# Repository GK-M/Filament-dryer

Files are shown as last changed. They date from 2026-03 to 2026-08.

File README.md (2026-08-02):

# Filament Dryer

**🇬🇧 English** · [🇵🇱 Polski](README.pl.md)

A 250 W heated drying chamber for 3D-printing filament, built from scratch: mechanics designed in
Autodesk Inventor and 3D-printed, electronics wired on a prototype board, firmware written for an
ESP32-C3 — first as a single Arduino sketch, then rewritten on **FreeRTOS** with tasks, queues and
over-the-air updates.

<p align="center">
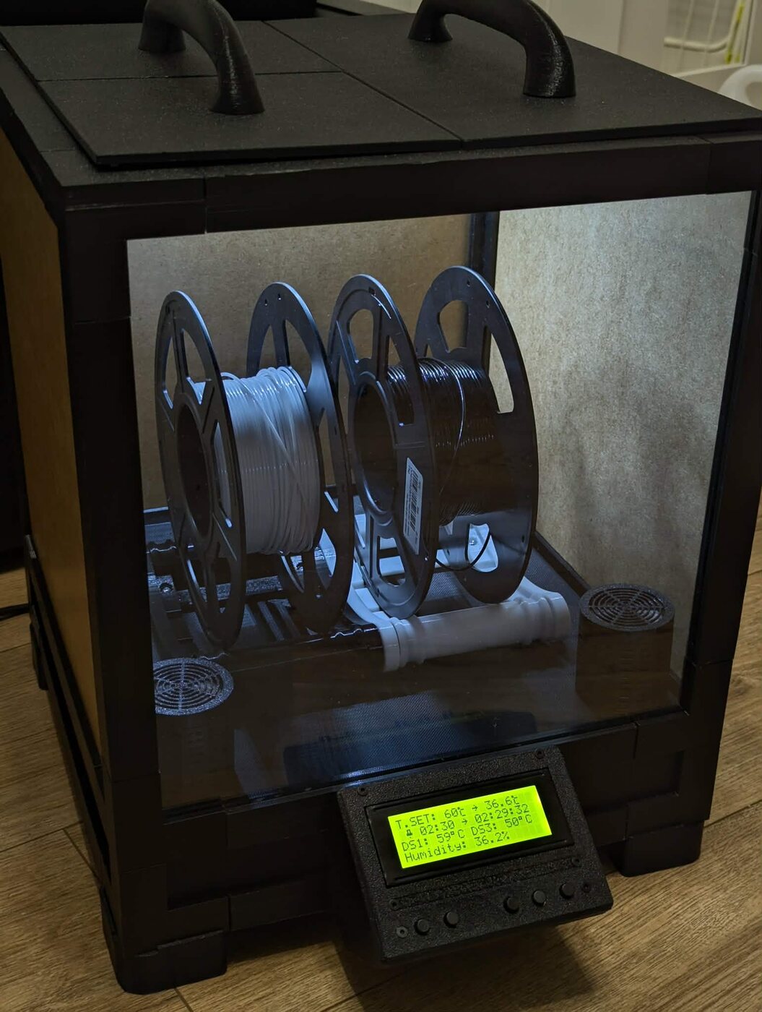
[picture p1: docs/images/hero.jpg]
Assembled filament dryer with two spools inside
  
</p>

<p align="center">
  
  
  
  
  
</p>

---

## Table of contents

| Document | What is inside |
|---|---|
| **[📸 Build log](docs/en/build-log.md)** | Photos from the whole build, stage by stage |
| [🔧 Hardware](docs/en/hardware.md) | Bill of materials, pin map, power rails, CAD & STL files |
| [💻 Firmware](docs/en/firmware.md) | FreeRTOS task/queue architecture, PID loop, UI, OTA |
| [📝 Changelog](docs/en/changelog.md) | What changed between v1, v2 and v3 |
| [🗺️ Roadmap](docs/en/roadmap.md) | Planned features and known issues |

---

## What it does

Wet filament prints badly — stringing, popping, weak layer adhesion. This box heats a sealed chamber
to a set temperature, holds it with a PID loop, and runs for a time you dial in on the front panel.

* **Set a temperature** (0–100 °C in 5 °C steps; ~70 °C is the practical ceiling of the enclosure)
* **Set a drying time** (15 min per click, up to 24 h) — the heater switches off when it elapses
* **Watch everything live** on a 20×4 LCD: chamber temperature, humidity, mat temperatures,
  PWM duty, remaining time, Wi-Fi status
* **Tune the PID on the device** — Kp/Ki/Kd are edited with the buttons and stored in flash,
  so they survive a reboot
* **Flash new firmware without a cable** — ArduinoOTA over Wi-Fi

## How it works

```
                 ┌──────────── ESP32-C3 ────────────┐
  AHT10  ──I²C──▶│  chamber temp ──▶ PID ──▶ PWM ───┼──▶ MOSFET ──▶ 3× heating mat (250 W)
  BMP280 ──I²C──▶│  temp / pressure                 │
                 │                                  │
 3× DS18B20 ─1W─▶│  mat temp ──▶ over-temp cut-off ─┼──▶ setpoint forced to 0
                 │                                  │
  5× button ─IRQ▶│  UI state machine ───────────────┼──▶ LCD 20×4 (I²C)
                 │                                  ├──▶ fan PWM (humidity driven)
        Wi-Fi ──▶│  ArduinoOTA                      └──▶ LED strip PWM
                 └──────────────────────────────────┘
```

The PID acts on the **chamber air temperature** (AHT10). The DS18B20 sensors sit on the heating mats
and are used purely for safety: if any of them passes **110 °C** the setpoint and PWM output are
forced to zero, and heating is only re-armed once all mats drop below **70 °C**.

Full details: **[Firmware architecture](docs/en/firmware.md)** · **[Hardware](docs/en/hardware.md)**

## Key specifications

| | |
|---|---|
| Controller | ESP32-C3 (`esp32-c3-devkitm-1`), Arduino framework, FreeRTOS |
| Heating | 3× silicone mat 24 V with heatsinks — 2×100 W + 1×50 W = **250 W** |
| Max chamber temperature | ~70 °C |
| Process sensor | AHT10 (temperature + relative humidity) |
| Auxiliary sensors | BMP280 (temperature, pressure), 3× DS18B20 (mat / electronics temperature) |
| Actuator drive | MOSFET modules, LEDC PWM 20 kHz, 10-bit resolution |
| Power rails | 24 V (mats) · 12 V (fan, LED) · 5 V (ESP32), via DC-DC step-down converters |
| Interface | LCD 20×4 I²C @ `0x27`, 5 buttons, LED chamber lighting |
| Connectivity | Wi-Fi, ArduinoOTA firmware updates |
| Enclosure | 3D-printed PETG frame + 300×300 mm acrylic panels |

## Repository layout

```
filament-dryer/
├── docs/
│   ├── en/            English documentation
│   ├── pl/            Polish documentation
│   ├── images/        Build photos
│   └── media/         Build video
├── firmware/
│   ├── v1-arduino/    Original single-file Arduino sketch (kept for reference)
│   └── v3-freertos/   Current PlatformIO project — FreeRTOS, OTA, NVS
└── hardware/
    ├── v1/cad/        Inventor parts & assemblies, STEP, 3MF
    └── v2/stl/        Printable STL files (base, screen mount)
```

## Building the firmware

The current firmware is a [PlatformIO](https://platformio.org/) project.

```bash
git clone https://github.com/GK-M/Filament_dryer.git
cd Filament_dryer/firmware/v3-freertos

# Wi-Fi credentials are not in the repository — create them from the template
cp include/secrets.h.example include/secrets.h
$EDITOR include/secrets.h

pio run                 # build
pio run -t upload       # flash (OTA by default — see below)
pio device monitor      # serial log
```

`platformio.ini` is configured for **OTA upload** to a fixed address:

```ini
upload_protocol = espota
upload_port = 192.168.1.15
```

For the first flash — or any time the board is not on the network — comment those two lines out and
upload over USB. The static IP is also set in `src/main.cpp`; change both to match your network.

## Status

v1 and v2 are complete and working. **v3 is under active development** — the firmware runs, but a
few screens and the fan control loop are still unfinished. Everything known to be incomplete or
buggy is listed openly in the [roadmap](docs/en/roadmap.md#known-issues).

## Licence

Released under the [MIT Licence](LICENSE).

> ⚠️ **Safety note.** This device draws 250 W of heating power and runs unattended for hours.
> The firmware over-temperature cut-off is a software safeguard, not a substitute for a proper
> thermal fuse, an adequately rated power supply and correctly sized wiring. Build and use at your
> own risk.

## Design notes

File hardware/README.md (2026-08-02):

# Hardware

Full documentation: **[English](../docs/en/hardware.md)** · **[Polski](../docs/pl/sprzet.md)**

```
v1/cad/   Autodesk Inventor parts (.ipt) and assemblies (.iam),
          plus neutral STEP (.stp) exports and sliced 3MF files.
v2/stl/   Printable STL files from version 2.
```

## Print settings

| Part | Material | Notes |
|---|---|---|
| Frame, corners, brackets | PETG | ~1 kg total for the full set |
| Display mount (`screen_mount.stl`, `screen_v2.stl`) | **ABS** | sits near the warm chamber wall; PETG softens there |
| Base (`base.stl`) | PETG | v2 perforation pattern — improves airflow and warm-up time |

## A note on filenames

The Inventor files keep their original Polish names. Inventor assemblies reference their component
parts *by filename*, so renaming any `.ipt` would break every `.iam` that uses it. An English
translation table is in the [hardware documentation](../docs/en/hardware.md#cad-sources--hardwarev1cad).

If you only want to print, use the `.stp` and `.3mf` files — they stand alone.

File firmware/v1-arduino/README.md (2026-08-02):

# Firmware v1 — Arduino sketch

*Historical. Kept for reference; superseded by [v3](../v3-freertos/).*

The original firmware: a single 729-line `.ino` file with one `loop()` handling sensor reads, the PID
loop, LCD redraws and button polling in sequence.

It worked and dried filament, but it showed the limits of the approach:

* the LCD flickered on every full redraw
* button presses were dropped while the display was being written
* every new feature had to be woven into the same growing loop
* configuration was spread across dozens of `#define`s and globals

Those problems are what motivated the [FreeRTOS rewrite](../v3-freertos/). Reading the two side by
side is the clearest illustration of what the rewrite bought.

## Building

Open `filament_dryer_v1.ino` in the Arduino IDE, select an ESP32-C3 board, and install:

`LiquidCrystal_I2C` · `Adafruit AHTX0` · `Adafruit BMP280` · `OneWire` · `DallasTemperature` ·
`PID by Brett Beauregard`

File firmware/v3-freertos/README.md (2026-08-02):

# Firmware v3 — FreeRTOS

*Current firmware. See [architecture documentation](../../docs/en/firmware.md) · [dokumentacja architektury](../../docs/pl/firmware.md).*

PlatformIO project for the ESP32-C3, Arduino framework, built on FreeRTOS.

## Quick start

```bash
cp include/secrets.h.example include/secrets.h   # add your Wi-Fi credentials
pio run                                          # build
pio run -t upload                                # flash
pio device monitor                               # serial log
```

`platformio.ini` uploads over the air by default. For the **first flash**, or whenever the board is
not reachable on the network, comment out these two lines and connect over USB:

```ini
upload_protocol = espota
upload_port = 192.168.1.15
```

The same static IP is set in `src/main.cpp` — change both to match your network.

## Layout

```
include/
├── config.h            pins, timings, calibration constants, LCD glyphs
├── rtos_handles.h      queue/task handles, shared data structures, enums
├── secrets.h           Wi-Fi credentials — GIT-IGNORED, create it yourself
├── secrets.h.example   template for the above
└── tasks/              one header per task
src/
├── main.cpp            queue and task creation, Wi-Fi, OTA
└── tasks/
    ├── button_task.cpp   ISR, debounce, auto-repeat, UI state machine
    ├── control_task.cpp  PID loop, PWM output, over-temperature cut-off
    ├── display_task.cpp  all LCD screens, countdown
    ├── fan_task.cpp      fan PWM
    ├── led_task.cpp      chamber LED PWM
    ├── log_task.cpp      serialises log messages onto Serial
    └── sensor_task.cpp   DS18B20, AHT10, BMP280
```

## Dependencies

Resolved automatically by PlatformIO from `platformio.ini`:

| Library | Purpose |
|---|---|
| `paulstoffregen/OneWire` | 1-Wire bus |
| `milesburton/DallasTemperature` | DS18B20 |
| `adafruit/Adafruit BMP280 Library` | BMP280 |
| `adafruit/Adafruit AHTX0` | AHT10 |
| `marcoschwartz/LiquidCrystal_I2C` | LCD 20×4 |
| `br3ttb/PID` | PID controller |

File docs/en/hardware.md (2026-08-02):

# Hardware

[← back to README](../../README.md) · [🇵🇱 wersja polska](../pl/sprzet.md)

---

## Bill of materials

### Electronics

| Qty | Part | Notes |
|:--:|---|---|
| 1 | ESP32-C3 dev board | `esp32-c3-devkitm-1`, Wi-Fi + USB CDC |
| 3 | MOSFET module | low-side switching of the heating mats |
| 3 | DC-DC step-down converter | generates the 12 V and 5 V rails from 24 V |
| 1 | AHT10 | I²C temperature + relative humidity — **PID process sensor** |
| 1 | BMP280 | I²C temperature + pressure |
| 3 | DS18B20 | 1-Wire, on the heating mats / electronics bay — safety cut-off |
| 1 | LCD 20×4 with I²C backpack | address `0x27` |
| 5 | Push button | menu navigation, momentary, to GND |
| 1 | Rocker switch | mains ON/OFF |
| 1 | Prototype board | carries the ESP32 and the wiring |
| 1 | LED strip | chamber lighting, PWM dimmable |
| 1 | Fan, 120 mm | air circulation, PWM controlled |
| 1 | Power supply, 250 W / 24 V | sized for all three mats at once |
| 1 | XT60 connector | main DC feed |
| — | Wire | sized for 24 V / ~10 A on the heater side |

### Heating

| Qty | Part |
|:--:|---|
| 2 | Silicone heating mat 100 W / 24 V |
| 1 | Silicone heating mat 50 W / 24 V |
| 3 | Heatsink (one per mat) |

### Mechanics

| Qty | Part |
|:--:|---|
| ~1 kg | PETG filament (frame, brackets, mounts) |
| — | ABS filament (display mount, v2 onwards — see [changelog](changelog.md)) |
| — | Acrylic sheet 300×300 mm |

---

## Power rails

```
        ┌── 24 V ──▶ 3× heating mat (via MOSFET modules)
 PSU ───┼── 12 V ──▶ fan + LED strip        (DC-DC step-down)
 250 W  └──  5 V ──▶ ESP32-C3               (DC-DC step-down)
```

The 24 V rail must carry the full 250 W of heating (≈10.4 A) — this is the part of the build where
wire gauge and connector rating actually matter.

---

## Pin map

Defined in [`firmware/v3-freertos/include/config.h`](../../firmware/v3-freertos/include/config.h).

| Function | GPIO | Notes |
|---|:--:|---|
| 1-Wire bus (3× DS18B20) | 3 | shared bus, sensors addressed individually |
| Heater PWM | 2 | LEDC channel 0, 20 kHz, 10-bit |
| Fan PWM | 4 | LEDC channel 2, 20 kHz, 10-bit |
| LED strip PWM | 7 | LEDC channel 1, 20 kHz, 10-bit |
| I²C SDA | 8 | 400 kHz — LCD, AHT10, BMP280 |
| I²C SCL | 9 | |
| Button — Enter | 1 | next screen |
| Button — Mode | 5 | cycles operating mode |
| Button — Screen | 10 | selects which value is being edited |
| Button — Decrease | 20 | with auto-repeat on hold |
| Button — Increase | 21 | with auto-repeat on hold |

All buttons are wired to GND and use the internal pull-ups (`INPUT_PULLUP`), so a press reads LOW.

### DS18B20 addresses

The 1-Wire sensors are addressed explicitly rather than by bus index, so swapping cables cannot
silently reassign which sensor is which. The addresses live in the `adrr_DS` namespace in
`config.h`; if you build your own unit, read your sensors' ROM codes and replace them there.

---

## Sensor roles

| Sensor | Measures | Used for |
|---|---|---|
| AHT10 | chamber air temperature, RH | **PID input** and fan control |
| BMP280 | temperature, pressure | display / logging only |
| DS18B20 ×3 | heating mat and electronics temperature | over-temperature safety cut-off |

The distinction matters: the PID regulates the *air*, not the mats. The mats always run hotter than
the chamber, which is exactly why they need their own independent safety sensors.

---

## Enclosure

The chamber is a 3D-printed frame holding 300×300 mm acrylic panels, rather than a fully printed
box. It uses far less filament, prints in manageable pieces, and lets you see the spools.

### CAD sources — `hardware/v1/cad/`

Autodesk Inventor parts (`.ipt`) and assemblies (`.iam`), with neutral `.stp` exports and sliced
`.3mf` files alongside them.

> **Filenames are intentionally left in Polish.** Inventor assemblies reference their component
> parts by filename — renaming the `.ipt` files would break every `.iam`. The table below is the
> translation key.

| Folder / file | English |
|---|---|
| `Front plexa/` | front acrylic panel |
| `obramówka do plexy/` | acrylic frame trim |
| `tył tył boxa/` | rear of the box |
| `tył za plexą/` | rear section, behind the acrylic |
| `OldVersions/` | superseded revisions |
| `Kątownik …` | angle bracket |
| `Narożnik …` | corner piece |
| `Klin_do_łączenia_34mm` | 34 mm joining wedge |
| `Koniec BOXa` | box end cap |
| `Część 1 / 2 / 3` | part 1 / 2 / 3 |
| `… na kabel` / `… przelotka` | with cable pass-through / grommet |
| `… z dziurą` | with hole |
| `… 3 wcięcia` | with three notches |
| `… x2`, `x3`, `x3szt` | print 2×, 3× |
| `górny` / `dolny` / `środek` | top / bottom / middle |
| `prawy` / `lewy` | right / left |

### Printable STL — `hardware/v2/stl/`

| File | Part | Material |
|---|---|---|
| `base.stl` | chamber base, v2 perforation pattern | ABS |
| `screen_mount.stl` | display mount | **ABS** (PETG deforms near the warm wall) |
| `screen_v2.stl` | display bezel, v2 | ABS |

---

## Assembly notes

* Fit the DS18B20 sensors in **direct contact** with the mats, under the heatsinks — an air gap
  makes the safety cut-off react far too late.
* Keep the 24 V heater wiring physically away from the I²C lines. The mats switch at 20 kHz and will
  happily inject noise into a long, unshielded I²C run.
* The AHT10 should sit in moving air away from the mats, otherwise the PID chases a hot spot instead
  of the chamber temperature.
* Route the mains side so the switch cuts everything upstream of the PSU.

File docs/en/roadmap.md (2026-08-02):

# Roadmap

[← back to README](../../README.md) · [🇵🇱 wersja polska](../pl/plany.md)

---

## Done

- [x] Drying timer
- [x] Over-temperature protection — setpoint forced to zero when a mat exceeds the limit
- [x] Dedicated display task
- [x] Firmware updates over Wi-Fi (ArduinoOTA)
- [x] PID gains editable on the device and persisted to flash
- [x] Wi-Fi status icon on the LCD

## Next

- [ ] **Fan control from humidity** — replace the current threshold with a proper control law
- [ ] **LED control** — hold *Enter* to toggle the backlight and the chamber LED together
- [ ] **Cooldown countdown** — when `pid_data.error` is set, show how long until the mats are back
      under the safe threshold instead of a static fault screen
- [ ] **Fault screen** — finish the `TEMP_ERROR` layout
- [ ] **Operating modes** — presets per filament type (PLA / PETG / ABS / Nylon) behind the
      `Mode` button, which currently only cycles an unused enum

## Later

- [ ] **MQTT or raw TCP/IP** — report state to a server
- [ ] **Remote control** — set temperature and time from outside the device
- [ ] **Notifications on completion** — PC, phone, e-mail
- [ ] **Double-walled chamber** — better insulation, faster warm-up, lower energy use
- [ ] **Filament feed-through** — let the printer draw filament straight from the dryer
- [ ] **Second, smaller fan** — improve moisture extraction

---

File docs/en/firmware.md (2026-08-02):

# Firmware

[← back to README](../../README.md) · [🇵🇱 wersja polska](../pl/firmware.md)

---

## Two generations

The firmware exists in two forms, both kept in the repository on purpose.

**[`firmware/v1-arduino/`](../../firmware/v1-arduino/)** — the original: one 729-line `.ino` file,
a single `loop()` doing sensor reads, PID, display refresh and button polling in sequence. It worked,
but the display flickered, button presses were missed while the LCD was being redrawn, and adding
anything meant threading it through the same loop.

**[`firmware/v3-freertos/`](../../firmware/v3-freertos/)** — the rewrite. Every concern became its
own FreeRTOS task, communicating through queues, with interrupt-driven buttons, persistent settings
and OTA updates. That is what this document describes.

---

## Task architecture

```mermaid
graph LR
    subgraph Inputs
        BTN[Button task<br/>prio 20]
        DS[DS18B20 task<br/>prio 6, 1 s]
        I2CS[AHT10/BMP280 task<br/>prio 5, 500 ms]
    end

    subgraph Logic
        CTRL[Control task<br/>prio 8, 10 ms]
    end

    subgraph Outputs
        DISP[Display task<br/>prio 15, 25 ms]
        FAN[Fan task<br/>prio 3]
        LED[LED task<br/>prio 2]
        LOG[Log task<br/>prio 11]
        OTA[OTA task<br/>prio 8]
    end

    BTN -->|xSetpointQueue| CTRL
    BTN -->|xDisplayQueue<br/>xTimerQueue| DISP
    DS -->|xDS18B20Queue| CTRL
    I2CS -->|xI2CsensorsQueue| CTRL
    I2CS -->|xI2CsensorsQueue| FAN
    CTRL -->|xControlDataQueue| DISP
    DS --> DISP
    I2CS --> DISP
    CTRL -.->|LOG| LOG
```

| Task | Priority | Stack | Period | Responsibility |
|---|:--:|:--:|:--:|---|
| `vButtonTask` | 20 | 16384 | event | Debounce, auto-repeat, UI state machine, NVS writes |
| `vDisplayTask` | 15 | 8192 | 25 ms | Renders all LCD screens, runs the countdown |
| `vLogTask` | 11 | 2048 | blocking | Serialises log messages onto `Serial` |
| `vControlTask` | 8 | 4096 | 10 ms | PID loop, PWM output, over-temperature cut-off |
| `vOtaTask` | 8 | 2048 | 100 ms | `ArduinoOTA.handle()`, Wi-Fi reconnect |
| `vTempSensorTask` | 6 | 2048 | 1 s | Reads the three DS18B20 sensors |
| `vHumTempSensorTask` | 5 | 4096 | 500 ms | Reads AHT10 and BMP280 over I²C |
| `vFanTask` | 3 | 1024 | 100 ms | Fan PWM from chamber humidity |
| `vLedTask` | 2 | 1024 | 50 ms | Chamber LED PWM |

`loop()` deletes itself with `vTaskDelete(NULL)` — the Arduino loop task is not used at all.

### Why these priorities

The button task sits highest because a missed press is immediately obvious to the user, while a
sensor reading arriving 20 ms late is not. Sensors sit low because they are periodic and tolerant of
jitter. The logger sits above the control loop deliberately: it must be able to drain its queue even
when everything else is busy, otherwise log messages are silently dropped exactly when you most want
to read them.

---

## Inter-task communication

Every queue except the log and button queues has **depth 1** and is written with `xQueueOverwrite`
and read with `xQueuePeek`. This is a deliberate pattern: these queues carry *current state*, not
events. A consumer always sees the newest value, a producer never blocks, and a slow consumer cannot
build a backlog of stale readings.

| Queue | Depth | Payload | Producer → consumer |
|---|:--:|---|---|
| `xDS18B20Queue` | 1 | `DS_sensors` | sensor → control, display |
| `xI2CsensorsQueue` | 1 | `I2C_sensors` | sensor → control, display, fan |
| `xSetpointQueue` | 1 | `PID_data` | button, control → control, display |
| `xControlDataQueue` | 1 | `Control_status` | control → display |
| `xTimerQueue` | 1 | `Timer_data` | button, display → display |
| `xDisplayQueue` | 1 | `Display_data` | button → display |
| `xButtonQueue` | 10 | `ButtonRAW` | **ISR** → button task |
| `xLogQueue` | 10 | `char[LOG_MSG_LEN]` | all tasks → log task |

The button and log queues are true event queues, so they are deeper and are drained with
`xQueueReceive`.

### The I²C mutex

The LCD, AHT10 and BMP280 all share one I²C bus, and the display task and sensor task run at
different rates and priorities. `xI2CMutex` guards every transaction; without it a display refresh
interleaving with a sensor read corrupts both.

---

## Control loop

```c
pid.SetTunings(Kp, Ki, Kd);
pid.Input = i2c_sensors.temp_aht;   // chamber air temperature
pid.Compute();
ledcWrite(0, pid.Output);           // 0..1023 → MOSFET → heating mats
```

* Library: `br3ttb/PID` in `DIRECT` mode
* Output range `0..1023`, matching the 10-bit LEDC resolution
* Sample time 10 ms
* Default gains `Kp = 2.25`, `Ki = 0.05`, `Kd = 0.0` — editable on the device, capped at
  `Kp ≤ 20`, `Ki ≤ 10`, `Kd ≤ 5`

`SetTunings()` is called on every iteration so that gains edited on the LCD take effect immediately,
without restarting the loop.

When the setpoint drops to zero the PID is briefly switched to `MANUAL`, its output forced to zero,
and switched back to `AUTOMATIC`. This resets the integral term — otherwise accumulated windup would
make the heater kick back on the moment a new setpoint is dialled in.

### Over-temperature protection

```
any DS18B20 > 110 °C  →  setpoint = 0, output = 0, error = true
all DS18B20 <  70 °C  →  error = false   (heating may resume)
```

The hysteresis band between the two thresholds is what stops the system oscillating in and out of
its fault state. Thresholds live in `Calibration::Max_DS_temperature` and
`Calibration::Temp_after_error` in `config.h`.

---

## Timer

The drying timer counts in `Timer_data`, incremented in 15-minute steps
(`Calibration::Button_Add_Time`) and clamped to 24 hours. It starts as soon as a non-zero time is
first dialled in, and the countdown itself runs inside the display task. When it reaches zero the
setpoint is zeroed and the UI switches to the `DONE` screen.

---

## User interface

Five buttons, all interrupt-driven. The ISR does the minimum possible — capture pin, edge and
timestamp, push into `xButtonQueue`, yield:

```c
void IRAM_ATTR isrButton(void* arg) {
    ButtonRAW event;
    event.pin  = (uint32_t)arg;
    event.edge = (digitalRead(event.pin) == LOW) ? PRESSED : RELEASED;
    event.timestamp = millis();
    xQueueSendFromISR(xButtonQueue, &event, &woken);
}
```

Debouncing (150 ms) and hold-to-repeat (400 ms) are handled in the task, not the ISR.

### Screens

| Screen | Shows |
|---|---|
| `Main` | Setpoint, chamber temperature, timer, countdown, DS18B20 readings, humidity, Wi-Fi icon |
| `Sensors_data` | Raw values from every sensor |
| `PID_cook` | Kp / Ki / Kd editor, live temperature and PWM duty |
| `PID_fan` | Placeholder — fan PID not implemented |
| `DONE` | Drying finished |
| `TEMP_ERROR` | Over-temperature fault |
| `MODE` | Operating mode — placeholder |

**Enter** advances the screen, **Screen** selects which value on that screen is being edited
(shown by a `>` marker), **Increase** / **Decrease** change it, **Mode** cycles the operating mode.

### Custom LCD glyphs

`config.h` defines six 5×8 characters: a degree symbol, a bell for the timer, two halves of a Wi-Fi
icon, and two halves of a crossed-out Wi-Fi icon for the disconnected state.

---

## Persistence

PID gains are stored in NVS through the `Preferences` API and reloaded at boot by the control,
display and button tasks. Changing a gain writes it immediately — so a tuning session survives a
power cut, and the dryer comes back with the gains you actually arrived at.

---

## Wi-Fi and OTA

A static IP (`192.168.1.15`) is configured in `main.cpp`, and `ArduinoOTA` runs under the hostname
`Filament Dryer`. The OTA task also handles reconnection: if the link drops, it retries every five
seconds. **Wi-Fi is never blocking** — the dryer boots, heats and regulates perfectly well with no
network at all, and the LCD simply shows the crossed-out Wi-Fi icon.

Credentials live in `include/secrets.h`, which is git-ignored. Copy `include/secrets.h.example` and
fill in your own.

---

## Known issues

Openly tracked in the [roadmap](roadmap.md#known-issues) rather than hidden.

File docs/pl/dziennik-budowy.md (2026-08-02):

# Dziennik budowy

[← powrót do README](../../README.pl.md) · [🇬🇧 English version](../en/build-log.md)

Zdjęcia z budowy wersji 1, mniej więcej w kolejności, w jakiej powstawała. Zmiany z wersji 2 są na
końcu.

---

## 1. Prototyp na płytce stykowej

Zanim cokolwiek powstało w CAD-zie, cała elektronika została złożona na blacie: ESP32-C3,
wyświetlacz, czujniki I²C i moduły MOSFET połączone luźnymi przewodami — tak, żeby sprawdzić
przypisanie pinów i odczyty czujników na działającym ekranie.

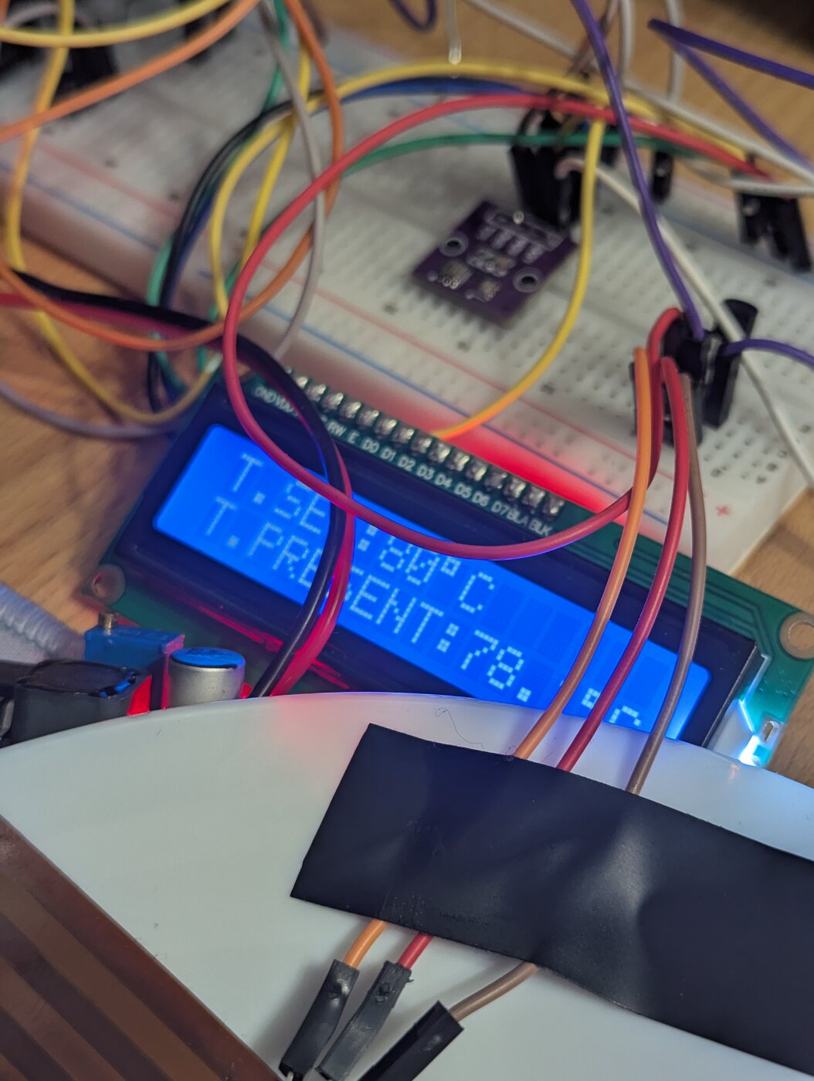
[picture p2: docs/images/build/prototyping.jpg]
Prototyp elektroniki na stole warsztatowym


To z tego etapu bierze się mapa pinów w
[`config.h`](../../firmware/v3-freertos/include/config.h) — piny zostały wybrane właśnie tutaj i
później już się nie zmieniały.

---

## 2. Druk ramy

Obudowa nie jest drukowanym pudełkiem. To zestaw drukowanych narożników i profili krawędziowych,
które spinają panele z pleksi 300×300 mm — zdecydowanie mniej filamentu, dużo krótszy czas druku
i komora, do której faktycznie widać.

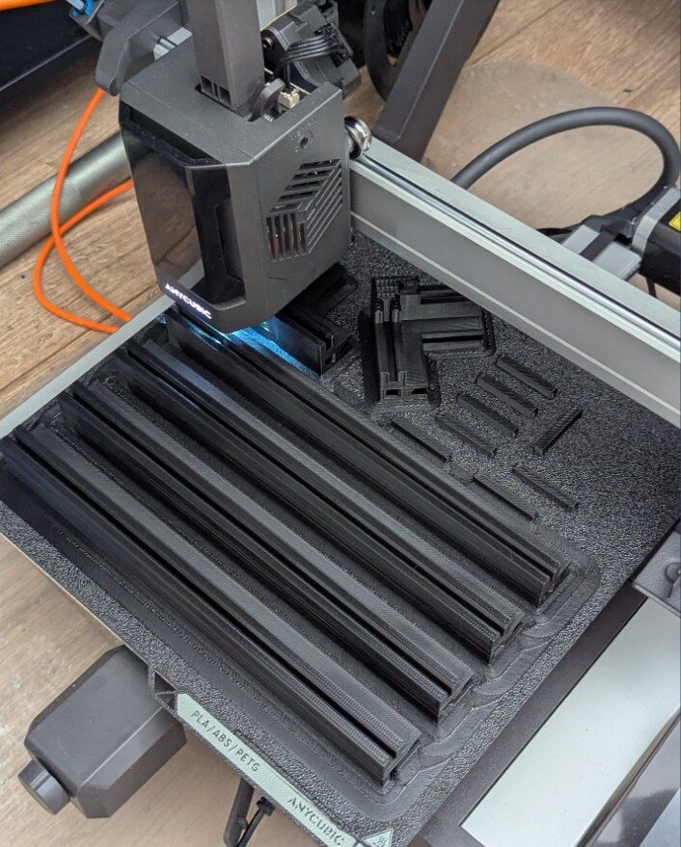
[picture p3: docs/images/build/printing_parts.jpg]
Elementy ramy na stole drukarki


Każda część została narysowana w Autodesk Inventor; pliki źródłowe są w
[`hardware/v1/cad/`](../../hardware/v1/cad/).

---

## 3. Wydrukowane części

Komplet narożników, kątowników i łączników rozłożony przed montażem. Kilka części ma po kilka
wersji — te nieaktualne leżą w folderach `OldVersions/` zamiast zostać skasowane, żeby historia
projektowania pozostała widoczna.

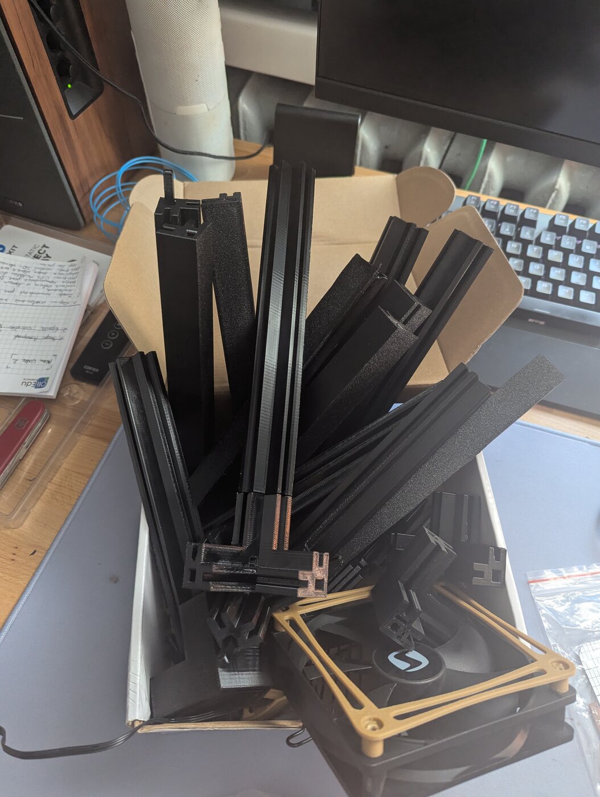
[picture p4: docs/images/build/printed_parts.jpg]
Zestaw wydrukowanych elementów ramy


---

## 4. Montaż obudowy

Rama i panele z pleksi składane w gotową komorę.

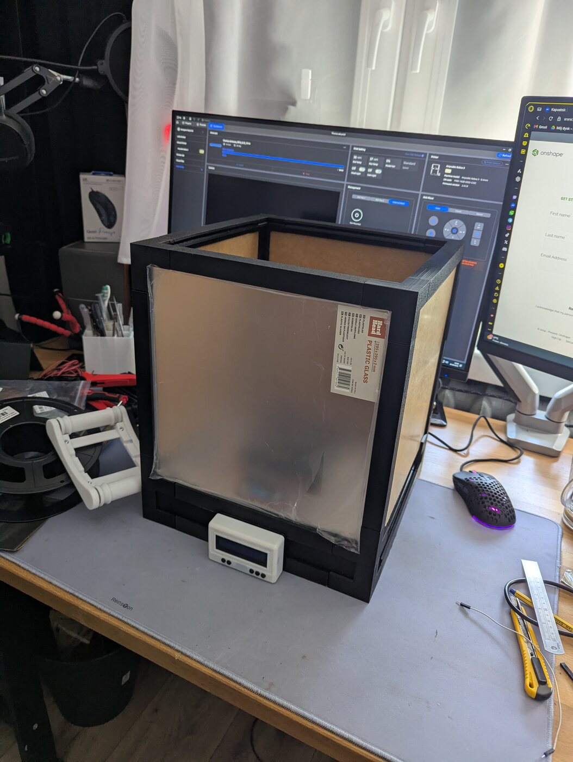
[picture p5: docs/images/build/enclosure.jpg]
Złożona obudowa


---

## 5. Wnętrze komory

Rozplanowanie środka: gdzie usiądą maty grzewcze wraz z radiatorami, jak przechodzi obok nich
powietrze i jak podeprzeć szpule, żeby swobodnie się obracały.

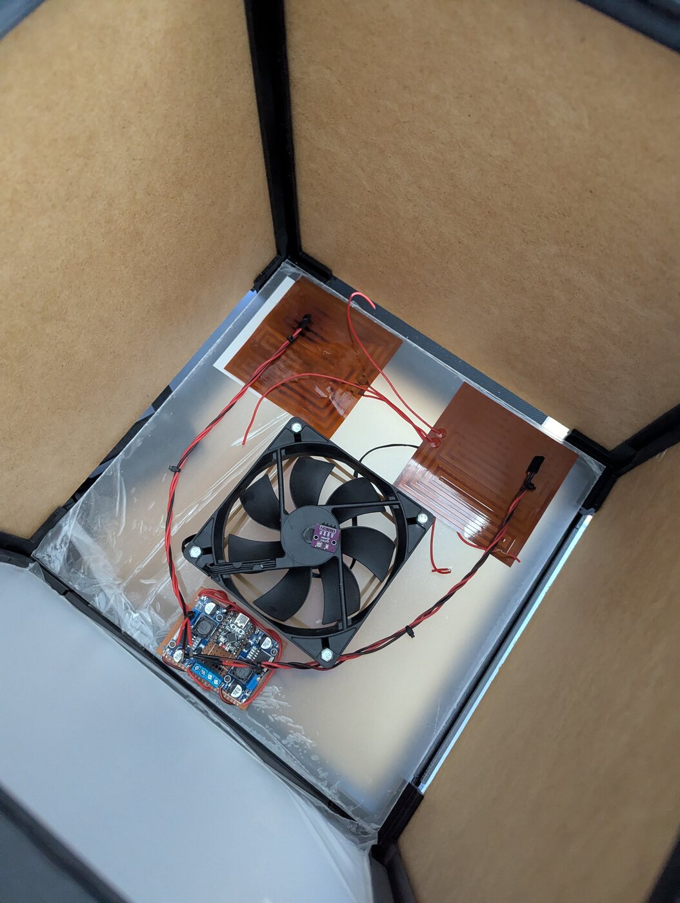
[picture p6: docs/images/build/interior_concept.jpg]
Wnętrze komory


---

## 6. Płytka sterownika i wyświetlacz

Elektronika przeniosła się ze stykówki na płytkę prototypową, a wyświetlacz trafił do drukowanego
mocowania na panelu przednim.

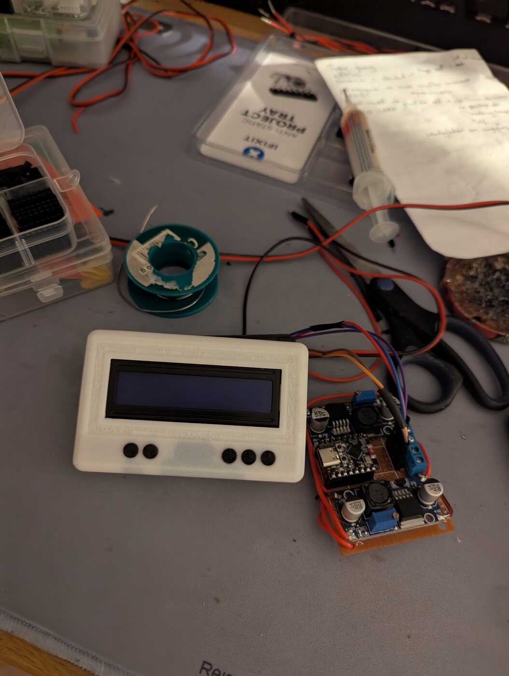
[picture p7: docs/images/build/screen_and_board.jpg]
Wyświetlacz i płytka sterownika


**Film:** [przegląd płytki sterownika](../media/controller_board.mp4) *(2,6 MB, bez dźwięku)*

<a href="../media/controller_board.mp4">
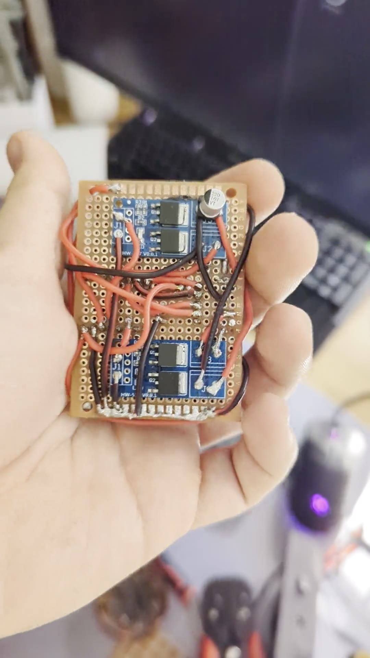
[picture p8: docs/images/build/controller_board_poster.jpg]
Kadr z filmu z płytką sterownika
  
</a>

---

## 7. Bezpieczeństwo

250 W grzania pracujące bez nadzoru przez wiele godzin wymaga szacunku. Przewody zostały dobrane pod
prąd, maty dostały własne czujniki DS18B20, a firmware — twarde zabezpieczenie termiczne, które
zeruje setpoint przy 110 °C i nie pozwala wrócić do grzania, dopóki każda mata nie spadnie poniżej
70 °C. Zobacz [`control_task.cpp`](../../firmware/v3-freertos/src/tasks/control_task.cpp).

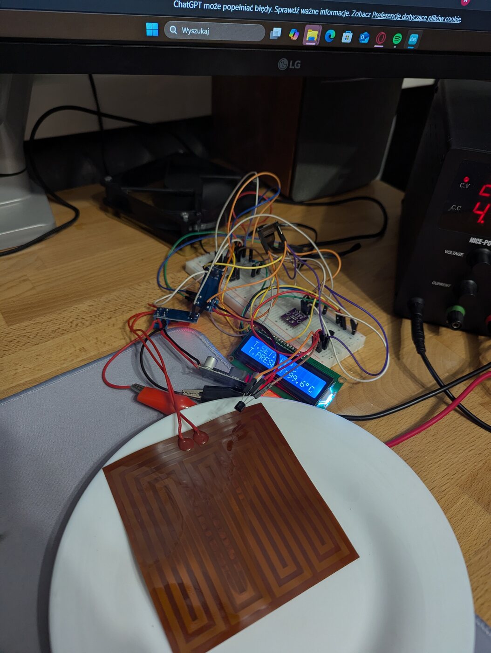
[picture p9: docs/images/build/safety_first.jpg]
Okablowanie i zabezpieczenia


---

## 8. Gotowa wersja 1

Gotowa suszarka

---

## Wersja 2 — poprawa wyświetlacza

Wyświetlacz 20×2 został zastąpiony przez 20×4, co wymusiło przepisanie kodu obsługi ekranu tak, żeby
wszystkie wartości nadal trafiały w sensowne miejsca. Samo mocowanie zostało przedrukowane z **ABS**
zamiast PETG, bo znajduje się blisko ciepłej ścianki komory, a PETG okazał się tam zbyt miękki.

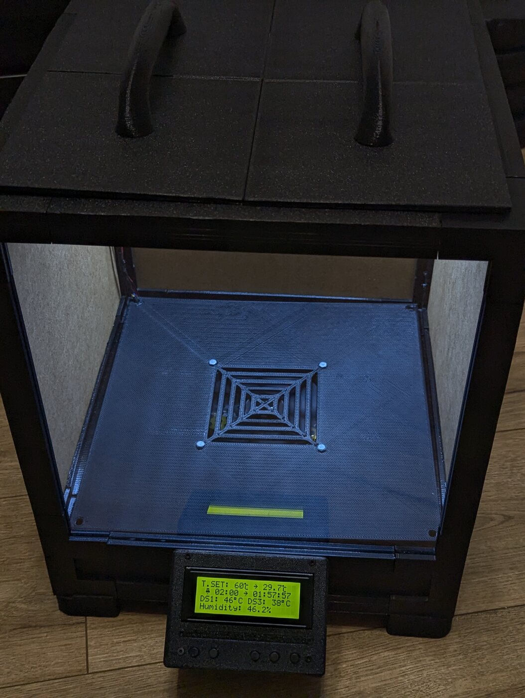
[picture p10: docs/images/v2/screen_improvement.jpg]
Nowe mocowanie wyświetlacza 20x4


Wersja 2 przyniosła też nową podstawę z gęstszym układem otworów dla lepszego przepływu powietrza
oraz trzecią matę grzewczą z własnym radiatorem — razem wyraźnie skróciło to czas nagrzewania.
Szczegóły w [historii zmian](historia-zmian.md).

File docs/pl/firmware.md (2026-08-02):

# Firmware

[← powrót do README](../../README.pl.md) · [🇬🇧 English version](../en/firmware.md)

---

## Dwie generacje

Firmware istnieje w dwóch wersjach i obie celowo zostały w repozytorium.

**[`firmware/v1-arduino/`](../../firmware/v1-arduino/)** — pierwotna: jeden plik `.ino` na 729 linii,
pojedyncza pętla `loop()` wykonująca po kolei odczyt czujników, PID, odświeżanie ekranu i
odpytywanie przycisków. Działała, ale ekran migotał, wciśnięcia przycisków ginęły w trakcie
przerysowywania LCD, a dodanie czegokolwiek oznaczało wplecenie tego w tę samą pętlę.

**[`firmware/v3-freertos/`](../../firmware/v3-freertos/)** — przepisana. Każda odpowiedzialność stała
się osobnym taskiem FreeRTOS, komunikującym się przez kolejki, z przyciskami na przerwaniach,
trwałymi ustawieniami i aktualizacją OTA. To właśnie ta wersja jest opisana poniżej.

---

## Architektura tasków

```mermaid
graph LR
    subgraph Wejscia["Wejścia"]
        BTN[Task przycisków<br/>prio 20]
        DS[Task DS18B20<br/>prio 6, 1 s]
        I2CS[Task AHT10/BMP280<br/>prio 5, 500 ms]
    end

    subgraph Logika
        CTRL[Task sterowania<br/>prio 8, 10 ms]
    end

    subgraph Wyjscia["Wyjścia"]
        DISP[Task wyświetlacza<br/>prio 15, 25 ms]
        FAN[Task wentylatora<br/>prio 3]
        LED[Task LED<br/>prio 2]
        LOG[Task logowania<br/>prio 11]
        OTA[Task OTA<br/>prio 8]
    end

    BTN -->|xSetpointQueue| CTRL
    BTN -->|xDisplayQueue<br/>xTimerQueue| DISP
    DS -->|xDS18B20Queue| CTRL
    I2CS -->|xI2CsensorsQueue| CTRL
    I2CS -->|xI2CsensorsQueue| FAN
    CTRL -->|xControlDataQueue| DISP
    DS --> DISP
    I2CS --> DISP
    CTRL -.->|LOG| LOG
```

| Task | Priorytet | Stos | Okres | Odpowiedzialność |
|---|:--:|:--:|:--:|---|
| `vButtonTask` | 20 | 16384 | zdarzeniowo | Debounce, auto-powtarzanie, automat stanów UI, zapis do NVS |
| `vDisplayTask` | 15 | 8192 | 25 ms | Rysuje wszystkie ekrany LCD, prowadzi odliczanie |
| `vLogTask` | 11 | 2048 | blokująco | Serializuje komunikaty na `Serial` |
| `vControlTask` | 8 | 4096 | 10 ms | Pętla PID, wyjście PWM, zabezpieczenie termiczne |
| `vOtaTask` | 8 | 2048 | 100 ms | `ArduinoOTA.handle()`, ponowne łączenie z Wi-Fi |
| `vTempSensorTask` | 6 | 2048 | 1 s | Odczyt trzech czujników DS18B20 |
| `vHumTempSensorTask` | 5 | 4096 | 500 ms | Odczyt AHT10 i BMP280 po I²C |
| `vFanTask` | 3 | 1024 | 100 ms | PWM wentylatora na podstawie wilgotności |
| `vLedTask` | 2 | 1024 | 50 ms | PWM oświetlenia komory |

`loop()` usuwa sam siebie przez `vTaskDelete(NULL)` — pętla Arduino w ogóle nie jest używana.

### Skąd takie priorytety

Task przycisków jest najwyżej, bo zgubione wciśnięcie użytkownik zauważa natychmiast, a odczyt
czujnika spóźniony o 20 ms — nie. Czujniki są nisko, bo są okresowe i tolerują jitter. Logger jest
świadomie ponad pętlą sterowania: musi móc opróżnić swoją kolejkę nawet wtedy, gdy reszta systemu
jest zajęta, inaczej komunikaty gubią się dokładnie wtedy, kiedy najbardziej chce się je przeczytać.

---

## Komunikacja między taskami

Każda kolejka poza logiem i przyciskami ma **głębokość 1**, jest zapisywana przez `xQueueOverwrite`
i czytana przez `xQueuePeek`. To celowy wzorzec: te kolejki przenoszą *aktualny stan*, a nie
zdarzenia. Odbiorca zawsze widzi najnowszą wartość, nadawca nigdy się nie blokuje, a wolny odbiorca
nie zbuduje zaległości przeterminowanych odczytów.

| Kolejka | Głębokość | Dane | Nadawca → odbiorca |
|---|:--:|---|---|
| `xDS18B20Queue` | 1 | `DS_sensors` | czujniki → sterowanie, wyświetlacz |
| `xI2CsensorsQueue` | 1 | `I2C_sensors` | czujniki → sterowanie, wyświetlacz, wentylator |
| `xSetpointQueue` | 1 | `PID_data` | przyciski, sterowanie → sterowanie, wyświetlacz |
| `xControlDataQueue` | 1 | `Control_status` | sterowanie → wyświetlacz |
| `xTimerQueue` | 1 | `Timer_data` | przyciski, wyświetlacz → wyświetlacz |
| `xDisplayQueue` | 1 | `Display_data` | przyciski → wyświetlacz |
| `xButtonQueue` | 10 | `ButtonRAW` | **ISR** → task przycisków |
| `xLogQueue` | 10 | `char[LOG_MSG_LEN]` | wszystkie taski → task logowania |

Kolejki przycisków i logów to prawdziwe kolejki zdarzeń, więc są głębsze i opróżniane przez
`xQueueReceive`.

### Mutex I²C

LCD, AHT10 i BMP280 dzielą jedną magistralę I²C, a task wyświetlacza i task czujników pracują z
różnymi częstotliwościami i priorytetami. `xI2CMutex` chroni każdą transakcję; bez niego odświeżenie
ekranu przeplecione z odczytem czujnika psuje obie operacje.

---

## Pętla regulacji

```c
pid.SetTunings(Kp, Ki, Kd);
pid.Input = i2c_sensors.temp_aht;   // temperatura powietrza w komorze
pid.Compute();
ledcWrite(0, pid.Output);           // 0..1023 → MOSFET → maty grzewcze
```

* Biblioteka: `br3ttb/PID` w trybie `DIRECT`
* Zakres wyjścia `0..1023`, zgodny z 10-bitową rozdzielczością LEDC
* Czas próbkowania 10 ms
* Nastawy domyślne `Kp = 2,25`, `Ki = 0,05`, `Kd = 0,0` — edytowalne z urządzenia, ograniczone do
  `Kp ≤ 20`, `Ki ≤ 10`, `Kd ≤ 5`

`SetTunings()` wywoływane jest w każdej iteracji, dzięki czemu nastawy zmienione na LCD działają
natychmiast, bez restartu pętli.

Gdy setpoint spada do zera, PID jest na chwilę przełączany w `MANUAL`, jego wyjście zerowane, po czym
wraca do `AUTOMATIC`. To resetuje człon całkujący — bez tego nagromadzone nasycenie sprawiłoby, że
grzałka natychmiast ruszyłaby przy wpisaniu nowej wartości zadanej.

### Zabezpieczenie przed przegrzaniem

```
którykolwiek DS18B20 > 110 °C  →  setpoint = 0, wyjście = 0, error = true
wszystkie DS18B20  <  70 °C   →  error = false   (grzanie może wrócić)
```

Histereza między progami jest tym, co powstrzymuje system przed oscylowaniem wokół stanu awarii.
Progi znajdują się w `Calibration::Max_DS_temperature` i `Calibration::Temp_after_error` w
`config.h`.

---

## Timer

Czas suszenia liczony jest w strukturze `Timer_data`, zwiększany co 15 minut
(`Calibration::Button_Add_Time`) i ograniczony do 24 godzin. Startuje w momencie pierwszego
ustawienia niezerowego czasu, a samo odliczanie działa wewnątrz taska wyświetlacza. Po dojściu do
zera setpoint jest zerowany, a interfejs przełącza się na ekran `DONE`.

---

## Interfejs użytkownika

Pięć przycisków, wszystkie na przerwaniach. ISR robi absolutne minimum — zapisuje pin, zbocze i
znacznik czasu, wrzuca do `xButtonQueue` i oddaje sterowanie:

```c
void IRAM_ATTR isrButton(void* arg) {
    ButtonRAW event;
    event.pin  = (uint32_t)arg;
    event.edge = (digitalRead(event.pin) == LOW) ? PRESSED : RELEASED;
    event.timestamp = millis();
    xQueueSendFromISR(xButtonQueue, &event, &woken);
}
```

Debounce (150 ms) i auto-powtarzanie przy przytrzymaniu (400 ms) obsługiwane są w tasku, nie w ISR.

### Ekrany

| Ekran | Co pokazuje |
|---|---|
| `Main` | Wartość zadana, temperatura komory, timer, odliczanie, odczyty DS18B20, wilgotność, ikona Wi-Fi |
| `Sensors_data` | Surowe wartości ze wszystkich czujników |
| `PID_cook` | Edytor Kp / Ki / Kd, bieżąca temperatura i wypełnienie PWM |
| `PID_fan` | Miejsce zarezerwowane — PID wentylatora niezaimplementowany |
| `DONE` | Suszenie zakończone |
| `TEMP_ERROR` | Awaria — przekroczona temperatura |
| `MODE` | Tryb pracy — miejsce zarezerwowane |

**Enter** przechodzi do kolejnego ekranu, **Ekran** wybiera edytowaną wartość (oznaczoną znakiem
`>`), **Zwiększ** / **Zmniejsz** ją zmieniają, **Tryb** przełącza tryb pracy.

### Własne znaki LCD

`config.h` definiuje sześć znaków 5×8: symbol stopnia, dzwonek timera, dwie połówki ikony Wi-Fi
i dwie połówki przekreślonej ikony Wi-Fi dla stanu bez połączenia.

---

## Trwałość ustawień

Nastawy PID zapisywane są w NVS przez API `Preferences` i wczytywane przy starcie przez taski
sterowania, wyświetlacza i przycisków. Zmiana nastawy zapisuje ją natychmiast — dzięki temu sesja
strojenia przeżywa zanik zasilania, a suszarka wraca z nastawami, do których faktycznie się doszło.

---

## Wi-Fi i OTA

Stały adres IP (`192.168.1.15`) ustawiany jest w `main.cpp`, a `ArduinoOTA` działa pod nazwą hosta
`Filament Dryer`. Task OTA obsługuje też ponowne łączenie: po zerwaniu połączenia ponawia próbę co
pięć sekund. **Wi-Fi nigdy nie blokuje** — suszarka bez sieci uruchamia się, grzeje i reguluje
zupełnie normalnie, a na LCD pojawia się po prostu przekreślona ikona Wi-Fi.

Dane logowania znajdują się w `include/secrets.h`, który jest wykluczony z gita. Skopiuj
`include/secrets.h.example` i uzupełnij własnymi.

---

## Znane problemy

Jawnie spisane w [planach](plany.md#znane-problemy), a nie ukryte.

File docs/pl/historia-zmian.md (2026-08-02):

# Historia zmian

[← powrót do README](../../README.pl.md) · [🇬🇧 English version](../en/changelog.md)

---

## v3 — przepisanie na FreeRTOS *(w trakcie)*

Największa zmiana w projekcie. Pojedyncza pętla Arduino została zastąpiona porządnym podziałem na
taski.

**Firmware**

* Całkowite przepisanie na **FreeRTOS** — każda odpowiedzialność w osobnym tasku, komunikacja przez
  kolejki ([szczegóły](firmware.md))
* Konfiguracja wyciągnięta do jednego pliku
  [`config.h`](../../firmware/v3-freertos/include/config.h) — piny, czasy, stałe kalibracyjne i progi
  w jednym miejscu zamiast rozsypanych `#define`
* **Przyciski na przerwaniach**, z debounce'em i auto-powtarzaniem obsługiwanymi w tasku, a nie w ISR
* **Aktualizacje OTA** przez Wi-Fi (ArduinoOTA) — koniec z rozkręcaniem panelu, żeby dostać się do
  portu USB
* **Nastawy PID edytowalne z urządzenia** i zapisywane do pamięci flash (NVS) — strojenie przeżywa
  restart
* Ikona statusu połączenia z Wi-Fi na LCD
* Nieblokująca obsługa sieci: brak Wi-Fi oznacza brak funkcji sieciowych, a nie martwą suszarkę
* Ogólna poprawa responsywności — koniec z migotaniem i gubionymi wciśnięciami przycisków

**Mechanika (planowana w tej wersji)**

* **Konstrukcja z podwójnymi ściankami** — lepsza izolacja, mniejsze zużycie energii i szybsze
  nagrzewanie
* **Otwory na przelot filamentu**, dzięki którym drukarka może pobierać filament bezpośrednio z
  suszarki w trakcie druku
* Dodatkowy mniejszy wentylator usprawniający pozbywanie się wilgoci

**W planach**

* MQTT i zdalne sterowanie
* Powiadomienia o zakończeniu suszenia — PC, telefon, e-mail

---

## v2 — poprawa wyświetlacza i grzania

* Wyświetlacz zmieniony z **20×2 na 20×4**, wraz z przeróbką kodu tak, żeby wszystkie wartości
  poprawnie rozłożyły się na większym ekranie
* Mocowanie ekranu przedrukowane z **ABS zamiast PETG** — znajduje się blisko ciepłej ścianki
  komory, a PETG w tym miejscu mięknął
* Nowa podstawa z **gęstszym układem otworów**, poprawiająca przepływ powietrza i skracająca czas
  nagrzewania
* Dodana **trzecia mata grzewcza** wraz z własnym radiatorem

Ulepszony wyświetlacz 20x4

---

## v1 — pierwsza działająca suszarka

Pierwotna konstrukcja: drukowana rama z panelami z pleksi, ESP32-C3 na płytce prototypowej,
regulacja PID grzania, interfejs na LCD i timer suszenia — wszystko w jednym szkicu Arduino.

Zdjęcia z tego etapu znajdują się w [dzienniku budowy](dziennik-budowy.md).

Szkic v1 został zachowany w pliku
[`firmware/v1-arduino/filament_dryer_v1.ino`](../../firmware/v1-arduino/filament_dryer_v1.ino).

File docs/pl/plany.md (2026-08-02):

# Plany rozwoju

[← powrót do README](../../README.pl.md) · [🇬🇧 English version](../en/roadmap.md)

---

## Zrobione

- [x] Timer suszenia
- [x] Zabezpieczenie termiczne — zerowanie wartości zadanej po przekroczeniu limitu na macie
- [x] Osobny task wyświetlacza
- [x] Aktualizacja firmware'u przez Wi-Fi (ArduinoOTA)
- [x] Nastawy PID edytowalne z urządzenia i zapisywane do pamięci flash
- [x] Ikona statusu Wi-Fi na LCD

## Następne w kolejce

- [ ] **Sterowanie wentylatorem od wilgotności** — zastąpienie obecnego progu prawdziwym prawem
      regulacji
- [ ] **Obsługa LED** — przytrzymanie *Enter* włącza i wyłącza podświetlenie ekranu razem z LED-em
      komory
- [ ] **Odliczanie do schłodzenia** — gdy `pid_data.error` jest ustawione, pokazywanie czasu
      pozostałego do zejścia mat poniżej progu bezpieczeństwa zamiast statycznego ekranu awarii
- [ ] **Ekran awarii** — dokończenie układu `TEMP_ERROR`
- [ ] **Tryby pracy** — presety dla typów filamentu (PLA / PETG / ABS / Nylon) pod przyciskiem
      `Tryb`, który obecnie tylko przewija nieużywany enum

## Później

- [ ] **MQTT albo czyste TCP/IP** — raportowanie stanu na serwer
- [ ] **Zdalne sterowanie** — ustawianie temperatury i czasu spoza urządzenia
- [ ] **Powiadomienia o zakończeniu** — PC, telefon, e-mail
- [ ] **Komora z podwójnymi ściankami** — lepsza izolacja, szybsze nagrzewanie, niższe zużycie
      energii
- [ ] **Przelot na filament** — możliwość pobierania filamentu przez drukarkę wprost z suszarki
- [ ] **Drugi, mniejszy wentylator** — lepsze pozbywanie się wilgoci

---

## Znane problemy

Rzeczy, które są obecnie błędne lub niedokończone — wypisane, a nie ukryte.

| # | Gdzie | Problem |
|:--:|---|---|
| 1 | `display_task.cpp`, `Screen::TEMP_ERROR` | Uszkodzone ciągi formatujące (`"%5.1%d"` z argumentem typu `float`). Ekran awarii wypisze śmieci — ten ekran jest niedokończony. |
| 2 | `sensor_task.cpp` | W linii logu z AHT10 argumenty są zamienione: temperatura trafia w miejsce opisane jako wilgotność i odwrotnie. Kosmetyka, ale myli przy czytaniu logów. |
| 3 | `config.h`, `adrr_DS::addr2` | Zbłąkany `\` na końcu linii przenosi kolejny komentarz, przez co notatka `//Temp podzespołów` zostaje połknięta. Nieszkodliwe, ale nie powinno tam być. |
| 4 | `rtos_handles.h`, `enum class Screen` | `COUNT` znajduje się w środku enuma, więc `Enter` przewija tylko cztery pierwsze ekrany. Działa, ale jest kruche — dodanie ekranu w złym miejscu po cichu zmieni nawigację. |
| 5 | `fan_task.cpp` | Sterowanie wentylatorem to próg dwustanowy przy 20 % RH (wypełnienie 1023 powyżej, 800 poniżej), a nie regulacja od wilgotności obiecywana w interfejsie. `Screen::PID_fan` to puste miejsce zarezerwowane. |
| 6 | `led_task.cpp` | Task ustawia LED na pełną jasność i dalej kręci pustą pętlę. Sterowanie LED-em i podświetleniem przez długie przytrzymanie nie jest zaimplementowane. |
| 7 | `button_task.cpp` | Timer suszenia startuje niejawnie przy pierwszym dodaniu czasu, a nie przy świadomym uruchomieniu. Ustawienie czasu i odejście od urządzenia niechcący rozpoczyna grzanie. |
| 8 | `control_task.cpp` | `pid.SetTunings()` wywoływane jest co 10 ms. Przy tej bibliotece nieszkodliwe, ale to praca wykonywana w każdej iteracji dla wartości zmieniającej się tylko przy naciśnięciu przycisku. |
| 9 | cały projekt | Brak testów automatycznych. Katalog `test/` to pusty szkielet PlatformIO. |

Zgłoszenia błędów i pull requesty mile widziane — załóż issue.

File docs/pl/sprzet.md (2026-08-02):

# Sprzęt

[← powrót do README](../../README.pl.md) · [🇬🇧 English version](../en/hardware.md)

---

## Lista części

### Elektronika

| Ilość | Element | Uwagi |
|:--:|---|---|
| 1 | Płytka ESP32-C3 | `esp32-c3-devkitm-1`, Wi-Fi + USB CDC |
| 3 | Moduł MOSFET | przełączanie mat grzewczych po stronie masy |
| 3 | Przetwornica step-down | wytwarza szyny 12 V i 5 V z 24 V |
| 1 | AHT10 | I²C, temperatura + wilgotność względna — **czujnik procesowy PID** |
| 1 | BMP280 | I²C, temperatura + ciśnienie |
| 3 | DS18B20 | 1-Wire, na matach grzewczych / przy elektronice — zabezpieczenie |
| 1 | LCD 20×4 z konwerterem I²C | adres `0x27` |
| 5 | Przycisk | nawigacja po menu, monostabilny, do masy |
| 1 | Włącznik kołyskowy | zasilanie ON/OFF |
| 1 | Płytka prototypowa | nośnik ESP32 i okablowania |
| 1 | Taśma LED | oświetlenie komory, ściemniana PWM |
| 1 | Wentylator 120 mm | obieg powietrza, sterowany PWM |
| 1 | Zasilacz 250 W / 24 V | dobrany pod wszystkie trzy maty naraz |
| 1 | Złącze XT60 | główne zasilanie DC |
| — | Przewody | dobrane pod 24 V / ok. 10 A po stronie grzania |

### Grzanie

| Ilość | Element |
|:--:|---|
| 2 | Mata grzewcza silikonowa 100 W / 24 V |
| 1 | Mata grzewcza silikonowa 50 W / 24 V |
| 3 | Radiator (po jednym na matę) |

### Mechanika

| Ilość | Element |
|:--:|---|
| ok. 1 kg | Filament PETG (rama, kątowniki, mocowania) |
| — | Filament ABS (mocowanie ekranu, od v2 — patrz [historia zmian](historia-zmian.md)) |
| — | Pleksi 300×300 mm |

---

## Zasilanie

```
        ┌── 24 V ──▶ 3× mata grzewcza (przez moduły MOSFET)
Zasilacz┼── 12 V ──▶ wentylator + taśma LED   (przetwornica step-down)
 250 W  └──  5 V ──▶ ESP32-C3                 (przetwornica step-down)
```

Szyna 24 V musi przenieść pełne 250 W grzania (ok. 10,4 A) — to ten fragment budowy, w którym
przekrój przewodu i obciążalność złączy naprawdę mają znaczenie.

---

## Mapa pinów

Zdefiniowana w [`firmware/v3-freertos/include/config.h`](../../firmware/v3-freertos/include/config.h).

| Funkcja | GPIO | Uwagi |
|---|:--:|---|
| Magistrala 1-Wire (3× DS18B20) | 3 | wspólna magistrala, czujniki adresowane pojedynczo |
| PWM grzałki | 2 | LEDC kanał 0, 20 kHz, 10 bitów |
| PWM wentylatora | 4 | LEDC kanał 2, 20 kHz, 10 bitów |
| PWM taśmy LED | 7 | LEDC kanał 1, 20 kHz, 10 bitów |
| I²C SDA | 8 | 400 kHz — LCD, AHT10, BMP280 |
| I²C SCL | 9 | |
| Przycisk — Enter | 1 | następny ekran |
| Przycisk — Tryb | 5 | przełącza tryb pracy |
| Przycisk — Ekran | 10 | wybiera edytowaną wartość |
| Przycisk — Zmniejsz | 20 | z auto-powtarzaniem przy przytrzymaniu |
| Przycisk — Zwiększ | 21 | z auto-powtarzaniem przy przytrzymaniu |

Wszystkie przyciski są podpięte do masy i korzystają z wewnętrznych podciągnięć (`INPUT_PULLUP`),
więc wciśnięcie daje stan niski.

### Adresy DS18B20

Czujniki 1-Wire są adresowane jawnie, a nie po indeksie na magistrali — dzięki temu przepięcie
przewodu nie przypisze po cichu odczytu do innego czujnika. Adresy znajdują się w przestrzeni nazw
`adrr_DS` w `config.h`; przy budowie własnego egzemplarza trzeba odczytać kody ROM swoich czujników
i podmienić je w tym miejscu.

---

## Rola czujników

| Czujnik | Mierzy | Do czego służy |
|---|---|---|
| AHT10 | temperatura powietrza w komorze, wilgotność | **wejście PID** i sterowanie wentylatorem |
| BMP280 | temperatura, ciśnienie | tylko wyświetlanie / logowanie |
| DS18B20 ×3 | temperatura mat i elektroniki | zabezpieczenie przed przegrzaniem |

To rozróżnienie jest istotne: PID reguluje *powietrze*, a nie maty. Maty zawsze są cieplejsze od
komory — i właśnie dlatego potrzebują własnych, niezależnych czujników zabezpieczających.

---

## Obudowa

Komora to drukowana rama spinająca panele z pleksi 300×300 mm, a nie w całości drukowane pudełko.
Zużywa znacznie mniej filamentu, drukuje się w wygodnych kawałkach i pozwala widzieć szpule.

### Pliki CAD — `hardware/v1/cad/`

Części (`.ipt`) i złożenia (`.iam`) z Autodesk Inventor, obok nich neutralne eksporty `.stp`
i pocięte pliki `.3mf`.

> **Nazwy plików celowo pozostały po polsku.** Złożenia Inventora odwołują się do części po nazwie
> pliku — zmiana nazw `.ipt` rozsypałaby każdy `.iam`. W wersji angielskiej dokumentacji znajduje
> się tabela tłumaczeń nazw.

### Pliki STL do druku — `hardware/v2/stl/`

| Plik | Element | Materiał |
|---|---|---|
| `base.stl` | podstawa komory, układ otworów z v2 | PETG |
| `screen_mount.stl` | mocowanie wyświetlacza | **ABS** (PETG odkształca się przy ciepłej ściance) |
| `screen_v2.stl` | ramka wyświetlacza, v2 | ABS |

---

## Uwagi montażowe

* Czujniki DS18B20 zamontuj w **bezpośrednim kontakcie** z matami, pod radiatorami — szczelina
  powietrzna sprawia, że zabezpieczenie reaguje o wiele za późno.
* Prowadź okablowanie 24 V grzałek fizycznie z dala od linii I²C. Maty przełączają się z
  częstotliwością 20 kHz i chętnie wprowadzą zakłócenia w długi, nieekranowany odcinek I²C.
* AHT10 powinien znajdować się w strumieniu powietrza, z dala od mat — inaczej PID goni za lokalnym
  gorącym punktem zamiast za temperaturą komory.
* Poprowadź stronę sieciową tak, żeby włącznik odcinał wszystko przed zasilaczem.

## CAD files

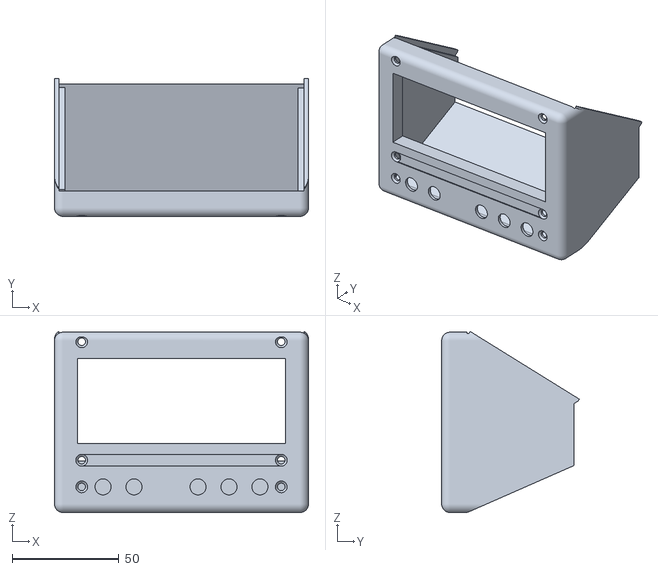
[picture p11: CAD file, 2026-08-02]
hardware/v2/stl/screen_v2.stl
119.0 x 64.5 x 84.8

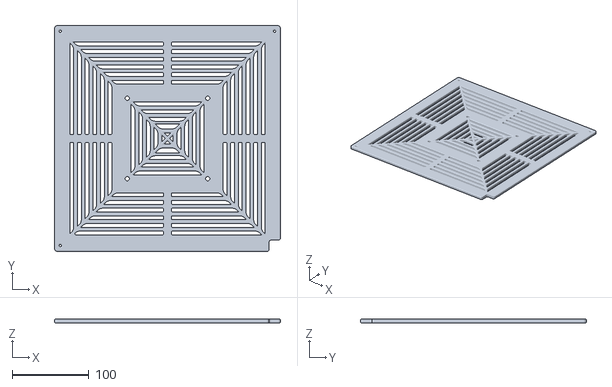
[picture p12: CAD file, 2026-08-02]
hardware/v2/stl/base.stl
295.0 x 295.0 x 5.00

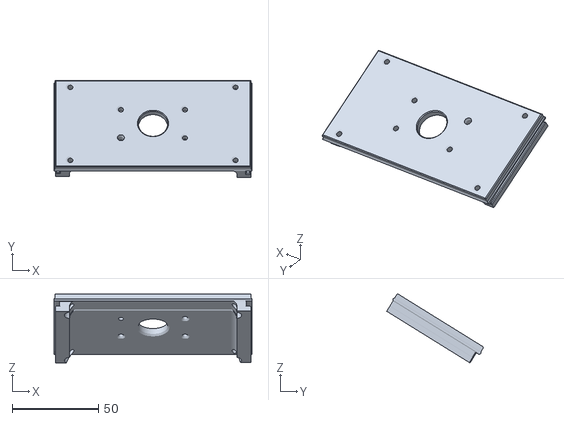
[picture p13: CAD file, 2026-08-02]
hardware/v2/stl/screen_mount.stl
115.0 x 56.2 x 40.0

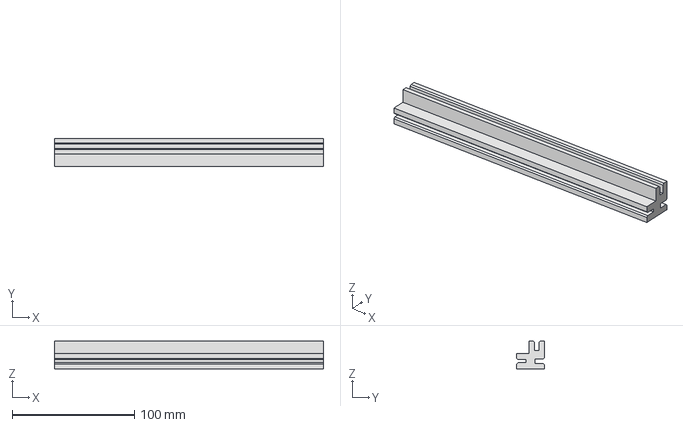
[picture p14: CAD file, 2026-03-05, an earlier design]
hardware/v1/cad/Front plexa/┼é─ůcznik d├│l po plexa x1.stp
220.0 x 22.5 x 22.5 mm

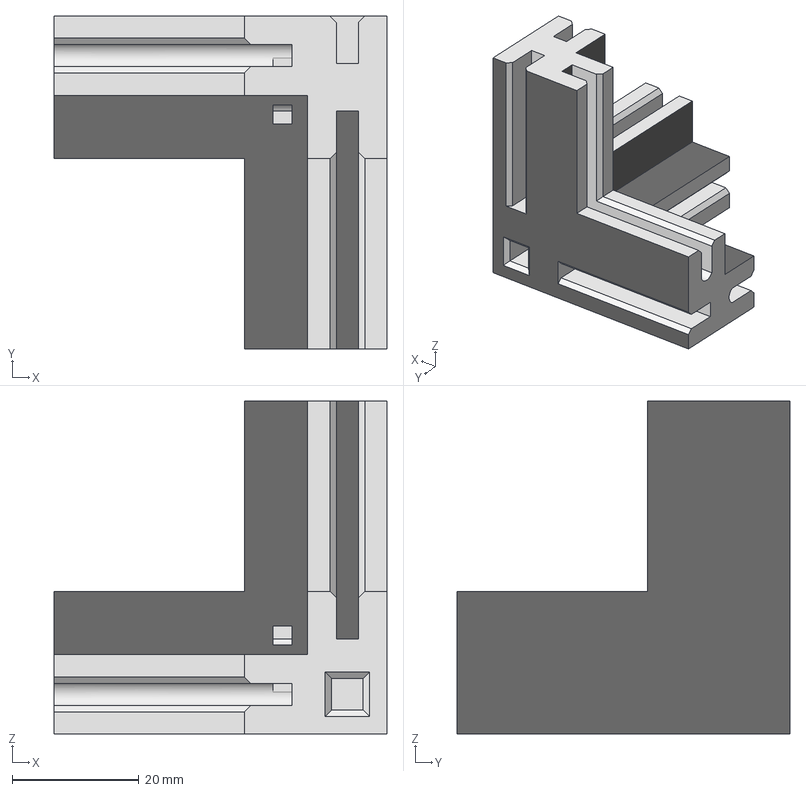
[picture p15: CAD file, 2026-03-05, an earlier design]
hardware/v1/cad/Naro┼╝nik ┼ÜrodekTY┼ü PRAWY I LEWY.stp
52.5 x 52.5 x 52.5 mm

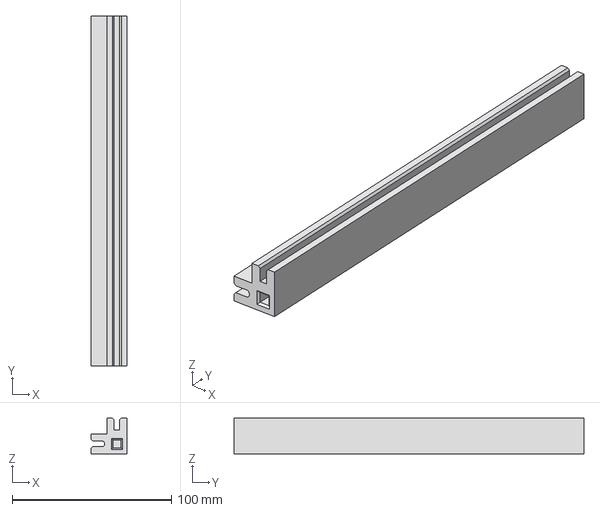
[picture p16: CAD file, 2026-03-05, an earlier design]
hardware/v1/cad/ty┼é ty┼é boxa/Naro┼╝nik na kabe x2 l.stp
22.5 x 220.0 x 22.5 mm
Narożnk na kabel
Część2

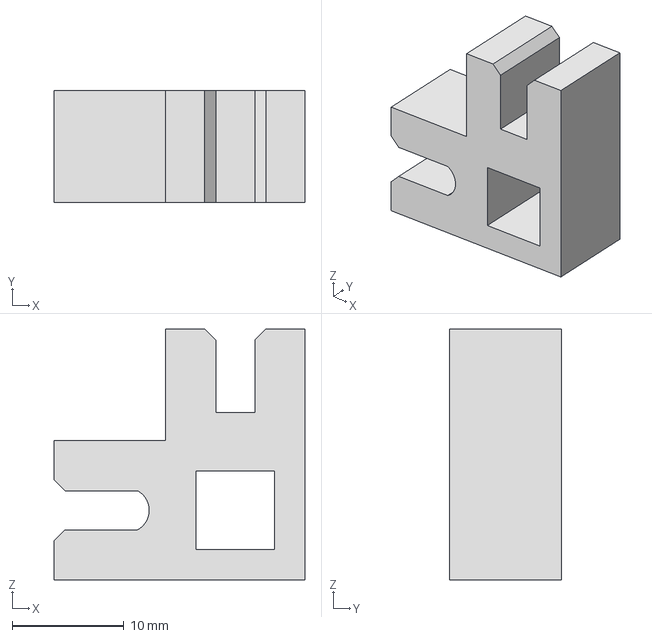
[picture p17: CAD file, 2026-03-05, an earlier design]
hardware/v1/cad/ty┼é za plex─ů/Naro┼╝nik 3mm_z_dziur─ů x2 .stp
22.5 x 10.0 x 22.5 mm
Narożni_10mm z dziurą
Część2

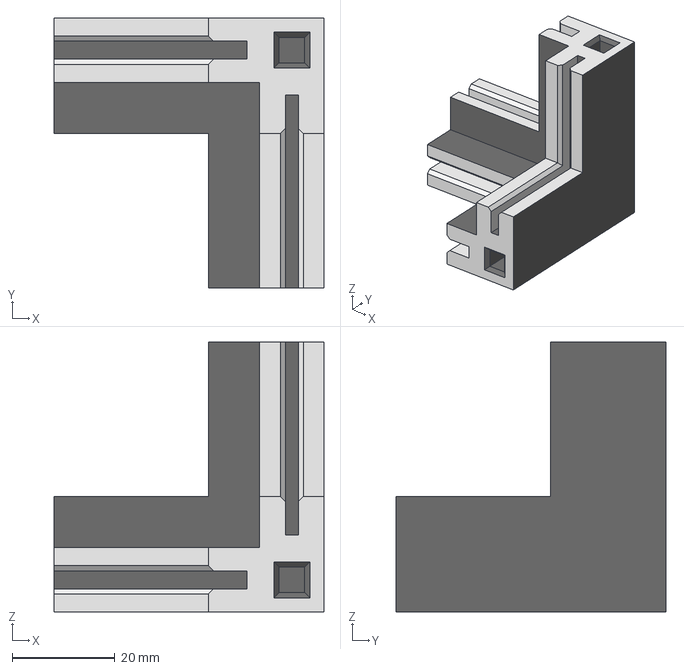
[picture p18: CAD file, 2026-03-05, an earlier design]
hardware/v1/cad/Front plexa/Naro┼╝nik g├│ra 1x2mm_2x3mm_dolny prawy i lewy.stp
52.5 x 52.5 x 52.5 mm

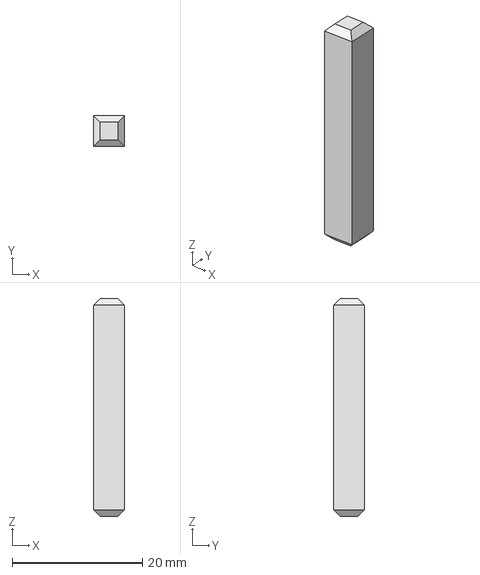
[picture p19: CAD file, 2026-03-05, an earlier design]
hardware/v1/cad/Klin_do_┼é─ůczenia_34mm.stp
4.70 x 4.70 x 33.5 mm

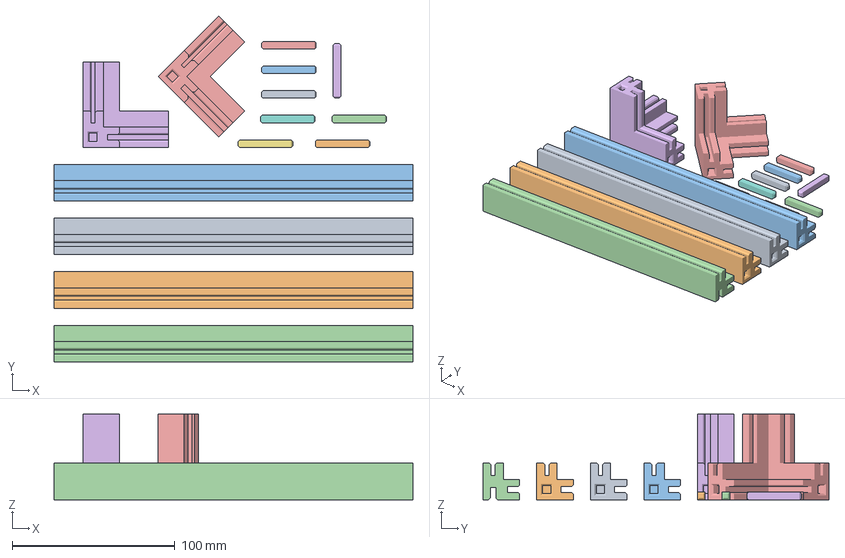
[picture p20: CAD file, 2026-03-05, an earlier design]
hardware/v1/cad/Front plexa/drukowanie_czwartek_praca.3mf
220.0 x 212.3 x 52.5 mm
Kątownik_220mm_pleaxe_na około x3szt.stp x 3
łącznik dól po plexa x1.stp
Narożnik góra 1x2mm_2x3mm_dolny prawy i lewy.stp x 2
Klin_do_łączenia_34mm.stp x 8

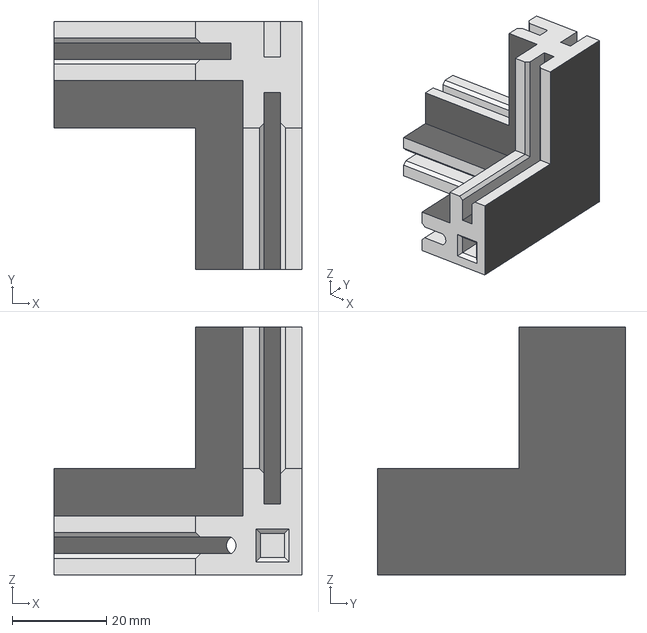
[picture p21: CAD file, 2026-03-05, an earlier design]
hardware/v1/cad/ty┼é ty┼é boxa/Naro┼╝nik ┼Ürodek przelotka x2.stp
52.5 x 52.5 x 52.5 mm
Część1
Część3

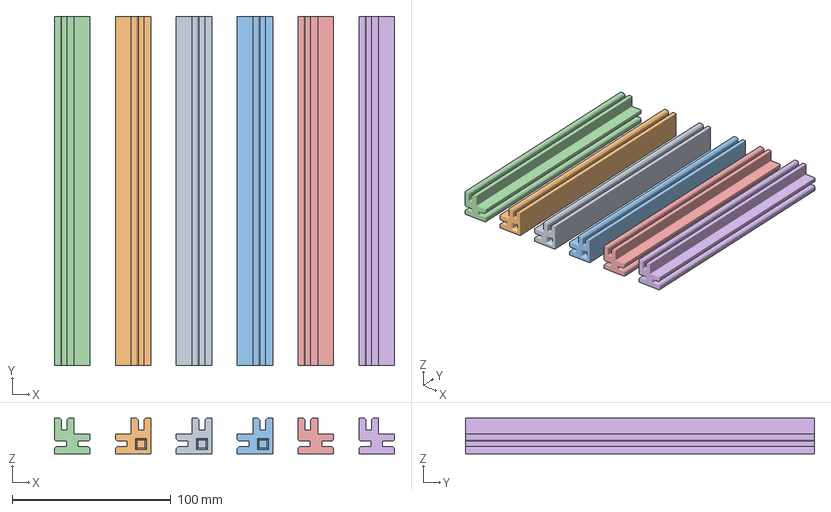
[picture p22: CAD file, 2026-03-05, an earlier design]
hardware/v1/cad/ty┼é za plex─ů/Naro┼╝niiki.3mf
214.5 x 220.0 x 22.5 mm
Narożni_220_3mm x2.stp
Narożni_220_3mm x3.stp x 2
Narożnik 3 wcięcia x3.stp x 3

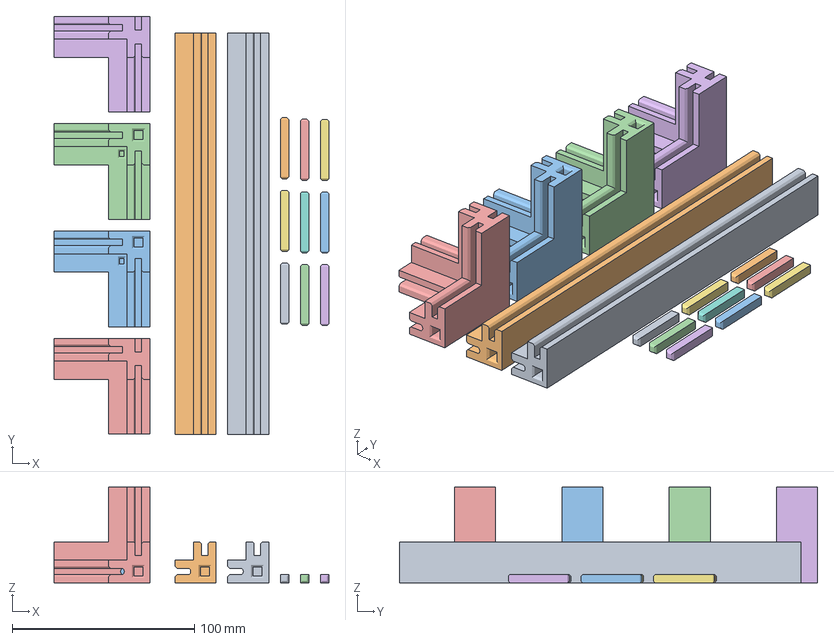
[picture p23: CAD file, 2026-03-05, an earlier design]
hardware/v1/cad/Koniec BOXa.3mf
150.7 x 229.2 x 52.5 mm
Narożnik na kabe x2 l.stp x 2
Kątownk z_dziurą x 2.stp x 2
Narożnik Środek przelotka x2.stp x 2
Klin_do_łączenia_34mm.stp x 9

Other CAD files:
hardware/v1/cad/ty┼é ty┼é boxa/K─ůtownk z_dziur─ů x 2.stp
hardware/v1/cad/ty┼é za plex─ů/Naro┼╝nik 3 wci─Öcia x3.stp
hardware/v1/cad/Naro┼╝nik ┼Ürodek LEWY Plexa.stp
hardware/v1/cad/Front plexa/K─ůtownik_220mm_pleaxe_na oko┼éo x3szt.stp
hardware/v1/cad/ty┼é za plex─ů/Naro┼╝ni_220_3mm x3.stp
hardware/v1/cad/Front plexa/K─ůtownik_trzynaci─Öcia_3mm.iam
hardware/v1/cad/Front plexa/┼é─ůcznik d├│l po plexa.iam
hardware/v1/cad/Klin_do_┼é─ůczenia_34mm.ipt
hardware/v1/cad/K─ůtownik normalny x 3.ipt
hardware/v1/cad/K─ůtownik normalny x 3.stp
hardware/v1/cad/K─ůtownik_219mm_pleaxe_na oko┼éo x3szt.stp
hardware/v1/cad/K─ůtownik┼Ťrodek plexa.stp
hardware/v1/cad/Naro┼╝nik 1x2mm_2x3mm_dolny prawy i lewy.stp
hardware/v1/cad/Naro┼╝nik ┼Ürodek Prawy Plexa.stp
hardware/v1/cad/Naro┼╝nik ┼ÜrodekTY┼ü PRAWY I LEWY.ipt
hardware/v1/cad/OldVersions/K─ůtownik┼Ťrodek plexa.0003.ipt
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

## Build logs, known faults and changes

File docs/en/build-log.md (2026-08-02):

# Build log

[← back to README](../../README.md) · [🇵🇱 wersja polska](../pl/dziennik-budowy.md)

Photographs from the build of version 1, roughly in the order things happened. Version 2 changes are
at the bottom.

---

## 1. Breadboard prototype

Before anything was designed in CAD, the whole electronics stack was assembled on the bench: the
ESP32-C3, the LCD, the I²C sensors and the MOSFET drivers, all wired loosely so the pin assignment
and the sensor readings could be verified against a working display.

Electronics prototype on the workbench

This stage is the reason the pin map in [`config.h`](../../firmware/v3-freertos/include/config.h)
looks the way it does — the pins were chosen here and never changed afterwards.

---

## 2. Printing the frame

The enclosure is not a printed box. It is a set of printed corner brackets and edge profiles that
clamp 300×300 mm acrylic panels — far less filament, far shorter print times, and a chamber you can
actually see into.

Frame parts on the printer bed

Every part was drawn in Autodesk Inventor; the sources are in
[`hardware/v1/cad/`](../../hardware/v1/cad/).

---

## 3. Printed parts

The full set of corners, brackets and connectors laid out before assembly. Several parts exist in
multiple revisions — the superseded ones are kept in the `OldVersions/` folders rather than deleted,
so the design history stays visible.

Set of printed frame parts

---

## 4. Assembling the enclosure

Frame and acrylic panels going together into the chamber.

Assembled enclosure

---

## 5. Chamber interior

Working out the internal layout: where the heating mats and their heatsinks sit, how air moves past
them, and how the spools are supported so they can turn freely.

Interior of the chamber

---

## 6. Controller board and display

The electronics moved off the breadboard onto a prototype board, and the LCD went into its printed
front-panel mount.

Display and controller board

**Video:** [controller board walkthrough](../media/controller_board.mp4) *(2.6 MB, no sound)*

<a href="../media/controller_board.mp4">
  Video still of the controller board
</a>

---

## 7. Safety

250 W of heating running unattended for hours deserves respect. Wiring was sized for the current,
the mats got dedicated DS18B20 sensors, and the firmware got a hard over-temperature cut-off that
zeroes the setpoint at 110 °C and refuses to re-arm until every mat is back under 70 °C — see
[`control_task.cpp`](../../firmware/v3-freertos/src/tasks/control_task.cpp).

Wiring and safety measures

---

## 8. Finished v2

Finished dryer

---

## Version 2 — display upgrade

The 20×2 LCD was replaced with a 20×4, which meant the display code had to be rewritten so that all
values still landed in sensible places. The mount itself was reprinted in **ABS** instead of PETG,
because it sits close to the warm chamber wall and PETG was too soft there.

New 20x4 display mount

Version 2 also brought a new base with a denser hole pattern for better airflow, and a third heating
mat with its own heatsink — together these cut the warm-up time noticeably. Details in the
[changelog](changelog.md).

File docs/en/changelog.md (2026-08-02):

# Changelog

[← back to README](../../README.md) · [🇵🇱 wersja polska](../pl/historia-zmian.md)

---

## v3 — FreeRTOS rewrite *(in progress)*

The largest change in the project. The single Arduino loop was replaced with a proper task-based
design.

**Firmware**

* Complete rewrite onto **FreeRTOS** — each concern isolated in its own task, communicating through
  queues ([details](firmware.md))
* Configuration extracted into a single [`config.h`](../../firmware/v3-freertos/include/config.h) —
  pins, timings, calibration constants and thresholds in one place instead of scattered `#define`s
* **Interrupt-driven buttons** with debouncing and hold-to-repeat handled in the task, not the ISR
* **OTA updates** over Wi-Fi via ArduinoOTA — no more unscrewing the panel to reach the USB port
* **PID gains editable on the device** and persisted to flash (NVS) — tuning survives a reboot
* Wi-Fi connection status icon on the LCD
* Non-blocking networking: no Wi-Fi means no network features, not a dead dryer
* General responsiveness improvements — no more flicker, no more missed button presses

**Mechanics (planned for this version)**

* **Double-walled construction** for better insulation, lower energy use and faster warm-up
* **Filament feed-through holes** so the printer can pull filament directly from the dryer while
  printing
* An additional smaller fan to improve moisture extraction

**Planned**

* MQTT and remote control
* Notifications when drying completes — PC, phone, e-mail

---

## v2 — display and heating improvements

* Display upgraded from **20×2 to 20×4**, with the display code reworked so all values are laid out
  correctly on the larger screen
* Display mount reprinted in **ABS instead of PETG** — it sits near the warm chamber wall, and PETG
  softened there
* New base with a **denser hole pattern**, improving airflow and cutting warm-up time
* **Third heating mat** added, with its own heatsink

Upgraded 20x4 display

---

## v1 — first working dryer

The original build: 3D-printed frame with acrylic panels, ESP32-C3 on a prototype board, PID heating
control, an LCD interface and a drying timer, all in a single Arduino sketch.

See the [build log](build-log.md) for photographs of this stage.

The v1 sketch is preserved at
[`firmware/v1-arduino/filament_dryer_v1.ino`](../../firmware/v1-arduino/filament_dryer_v1.ino).

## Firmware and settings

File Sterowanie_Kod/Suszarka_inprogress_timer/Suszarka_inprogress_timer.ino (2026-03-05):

#include <Wire.h>
#include <LiquidCrystal_I2C.h>
#include <Adafruit_AHTX0.h>
#include <Adafruit_BMP280.h>
//Biblioteki do DS18B20
#include <OneWire.h>
#include <DallasTemperature.h>

#include <PID_v1.h>

LiquidCrystal_I2C lcd(0x27, 20, 4);  // 16 kolumn, 2 wiersze
Adafruit_AHTX0 aht;
Adafruit_BMP280 bmp;

// Pin danych DS18B20
#define ONE_WIRE_BUS 3
#define PrzyciskEkran 10  // przycisk do GND (aktywny stan niski)
#define FAN_PWM 4         // pin do PWM wentylatora
#define COOK_PWM 2        // pin do PWM mata grzewcza
#define Increase 21       // zwiększanie wartości zadanej
#define Decrease 20       // zmniejszanie wartości zadanej
#define PrzyciskTryb 5    //zmiana trybów 5
#define Enter 1          //Zatwierdzenie 9
#define LedPin 7 //Pin do sterowania pwm
//scl - 9
//sca - 8

// j2 vin
//j3 vout
//czarny sda
//czerwony sdl

// Utworzenie obiektu OneWire i DallasTemperature
OneWire oneWire(ONE_WIRE_BUS);
DallasTemperature sensors(&oneWire);



bool backlightOn = true;  // zapamiętany stan podświetlenia
long long CzasDane = 0;
long CoIlePomiar = 1000;    // Co sekunde zbiera dane
int TimeOfflcd = 2 * 1000;  //Czas ile trzymać przycisk
int pTimeOfflcd;
bool LCDflaga = false;    //flaga to zmiany stanu przycisku
bool EnterFlaga = true;  //flaga to zatwierdzania TU MUSI BYC  TRUE
int strona = 1;           //pierwsza strona
int IleStron = 4;         //ile stron do przewijania
int Iletrybow = 3;
long long czasStrona = 0;
const int kana = 0;
const int freq = 1 * 1000;     //1k Hz - PWM dla wentylatora
const int freqCook = 1 * 1000;  //1k Hz - PWM dla grzałki
const int resolution = 10;      //10bit -> zakres duty 0-1023
float temp_aht = 0;
float hum_aht = 0;
bool next = 0;
unsigned long long czasStronap;
int Zadana = 0;
unsigned long long czasTryb = 0;

double tempDS_1 = 0;
double tempDS_2 = 0;
double tempDS_3 = 0;
double DS_2 = 0;
double DS_1 = 0;
double DS_3 = 0;

int tryb = 0;
bool Ptryb = 0;

//Zmienne do timera
uint32_t  SetCzas = 0;

bool FastCzasUp = true;
bool FastCzasDown = true;
unsigned long CzasEnterUp = 0;
unsigned long FastNextCharUp = 0;
unsigned long CzasEnterDown = 0;
unsigned long FastNextCharDown = 0;
const unsigned long debounceDelay = 150;
unsigned long DebounceTimeUp = 0;
unsigned long DebounceTimeDown = 0;
unsigned long ZapisCzasOdliczanie = 0;
uint32_t  StoperCzasMin = 0.0;
uint32_t  StoperCzasGodz = 0.0;
uint32_t  StoperCzasSek = 0.0;
unsigned long doubleStoperCzasGodz = 0.0;
uint32_t  ODLICZ = 0;

bool timerAktywny = false;

//Ekran Wyświetlanie:
uint32_t  SetCzasSek = 0;
uint32_t  SetCzasMin = 0;
uint32_t  SetCzasGodz = 0;

uint32_t czasEnter = 0;
uint32_t dwaczas = 0;

double Setpoint = 0;  // zadana (np. °C)
double Input = 0;     // pomiar
double Output = 0.0;  // wyjście PID (0..100)

// Nastawy (start: PI, bez D)
double Kp = 2.25, Ki = 0.05, Kd = 0.0;

int FAN_MOC = 0;
int RAW = 0;
int COOK_RAW = 0;
int TempGraniczna = 115;

// Led

bool StanLed = HIGH;

//Emotki

uint8_t Stopnie[] = {
  0b11000,
  0b11000,
  0b00111,
  0b01000,
  0b01000,
  0b01000,
  0b01000,
  0b00111
};

uint8_t Dzwonek[] = {
  0b01110,
  0b01010,
  0b01010,
  0b11111,
  0b11111,
  0b00000,
  0b00100,
  0b00000
};
inline void print2d(uint32_t v) {
        if (v < 10) lcd.print('0');
        lcd.print(v);
        }

uint32_t k;
inline void printTemp(uint32_t k) {
  if (k < 10){
    lcd.print("  ");
    }
  else if (k < 99 && k >10){
    lcd.print(" ");   
    }
    lcd.print(k);    
    }

void EnterFlagaa() {
  if (digitalRead(Enter) == LOW && millis()-czasEnter>200 ) {
    czasEnter = millis();
    EnterFlaga = !EnterFlaga;
    timerAktywny =  false;
    ZapisCzasOdliczanie = millis();
    
  }
  
}



  void SETCZAS() {
    // Obsługa Increase
    if (strona == 1 && !EnterFlaga && digitalRead(Increase) == 0 && millis() - DebounceTimeUp > debounceDelay) {
      SetCzas = SetCzas + 900000UL;
      FastCzasUp = false;
      CzasEnterUp = millis();
      FastNextCharUp = CzasEnterUp;
      DebounceTimeUp = millis();
      delay(100);
      Serial.printf("Wartość Zadana to %d\n", SetCzas );
    }

    if (!FastCzasUp && digitalRead(Increase) == 0) {
      if ((millis() - CzasEnterUp > 400) && (millis() - FastNextCharUp > 400)) {
        FastNextCharUp = millis();
        SetCzas = SetCzas + 900000UL;
        Serial.printf("Wartość Zadana to %d\n", SetCzas );
      }
    }

    if (digitalRead(Increase) == 1) FastCzasUp = true;

    // Obsługa Decrease
    if (strona == 1 && !EnterFlaga && digitalRead(Decrease) == 0 && millis() - DebounceTimeDown > debounceDelay) {
      SetCzas = SetCzas - 900000UL;
      FastCzasDown = false;
      CzasEnterDown = millis();
      FastNextCharDown = CzasEnterDown;
      DebounceTimeDown = millis();
      delay(100);
      Serial.printf("Wartość Zadana to %d\n", SetCzas );
    }


    if (!FastCzasDown && digitalRead(Decrease) == 0) {
      if ((millis() - CzasEnterDown > 400) && (millis() - FastNextCharDown > 400)) {
        FastNextCharDown = millis();
        SetCzas = SetCzas - 900000UL;
        Serial.printf("Wartość Zadana to %d\n", SetCzas );
      }
    }
    if (digitalRead(Decrease) == 1) FastCzasDown = true;

    //Zmiana Formatu
    SetCzas = constrain(SetCzas, 0, 86400000);  //max czas do ustawienia 24h

    SetCzasMin = (SetCzas / 60000UL) % 60U;
    SetCzasGodz = (SetCzas / 3600000UL);
  }


  void Odliczanie() {
    if ( EnterFlaga && !timerAktywny && SetCzas!=0) {
      timerAktywny = true;
      ZapisCzasOdliczanie = millis();
     
    }

    if (timerAktywny ) {

      ODLICZ = SetCzas - (millis() - ZapisCzasOdliczanie);
      ODLICZ = constrain(ODLICZ, 0UL, 86400000UL); 
      StoperCzasMin = (ODLICZ / 60000UL) % 60U;
      StoperCzasGodz = (ODLICZ / 3600000UL);
      StoperCzasSek = (ODLICZ / 1000UL) % 60U;
      
      }
    
      if(digitalRead(PrzyciskEkran) == 0 && digitalRead(Enter) == LOW){
        if(millis()-dwaczas>200){
          SetCzas = 0;
          ODLICZ = 0;
          StoperCzasMin = 0;
          StoperCzasGodz = 0;
          StoperCzasSek = 0;
          strona=1;
          dwaczas = millis();
        }
      }
          
    
    
   
      
      
    

    if (StoperCzasMin == 0 & StoperCzasGodz == 0 & StoperCzasSek == 0) {
      Zadana = 0;
      //SetCzas = 0;
      timerAktywny = false;
    }
  }



  void NextStrona() {

    if (digitalRead(PrzyciskEkran) == 0 && millis() - czasStrona > 200 && digitalRead(Enter) != LOW ) {
      czasStrona = millis();
      strona++;
      tryb = 0;
    }
    if (strona > IleStron) strona = 1;
  }
  void NextTryb() {
    if (digitalRead(PrzyciskTryb) == 0 && millis() - czasTryb > 200) {
      czasTryb = millis();
      tryb++;
      strona = 0;
    }
    if (tryb > Iletrybow) tryb = 1;
  }
  void ekranOff() {
    if (digitalRead(PrzyciskEkran) == 0 && !LCDflaga) {
      pTimeOfflcd = millis();
      LCDflaga = true;
    }
    if (digitalRead(PrzyciskEkran) == 1 && LCDflaga) {
      LCDflaga = false;
    }
    if (digitalRead(PrzyciskEkran) == 0 && LCDflaga) {
      if (millis() - pTimeOfflcd > TimeOfflcd) {
        // wciśnięty
        backlightOn = !backlightOn;
        StanLed = !StanLed;

        LCDflaga = false;
        if (backlightOn) {
          lcd.backlight();
          strona = 1;
          digitalWrite(LedPin,HIGH);

        } else {
          lcd.noBacklight();
          digitalWrite(LedPin, LOW);
        }
        
        delay(200);  // proste debounce
      }
    }
  }
  void PomiarZczujnikow() {
    if (millis() - CzasDane > CoIlePomiar) {
      CzasDane = millis();
      // AHT20: temp + wilgotność
      sensors_event_t hum, temp;
      aht.getEvent(&hum, &temp);

      temp_aht = temp.temperature;
      hum_aht = hum.relative_humidity;

      // BMP280: temp + ciśnienie
      float t_bmp = bmp.readTemperature();
      float p_hPa = bmp.readPressure() / 100.0f;

      //Temeratura DS18B20

      sensors.requestTemperatures();                 // rozpocznij pomiar
       tempDS_1 = sensors.getTempCByIndex(0);  // odczytaj pierwszy czujnik
       tempDS_2 = sensors.getTempCByIndex(1);  // odczytaj drugi czujnik
       tempDS_3 = sensors.getTempCByIndex(2);  // odczytaj trzeci czujnik

      DS_1 = tempDS_2;
      DS_2 = tempDS_2;
      DS_3 = tempDS_3;

      //Tworzenie Emotek
      lcd.createChar(0, Stopnie);  // Zapisz jako znak nr 0
      lcd.createChar(1, Dzwonek);  // Zapisz jako znak nr 1



      if (strona == 1) {
        
        if(Zadana == 0){
        lcd.setCursor(0, 0);
        lcd.print("T.SET:");
        lcd.print("  0");
        lcd.write(byte(0));  // znak stopni
        lcd.print(" ");
         }
        else if(Zadana<10){
          lcd.setCursor(0, 0);
          lcd.print("T.SET:");
          lcd.print("  ");
          lcd.print(Zadana);
          lcd.setCursor(9, 0);  
          lcd.write(byte(0));  // znak stopni
          lcd.print(" ");
          }
        else if(Zadana>9 && Zadana!=100){
          lcd.setCursor(0, 0);
          lcd.print("T.SET:");
          lcd.print(" ");
          lcd.print(Zadana);
          lcd.setCursor(9, 0);  
          lcd.write(byte(0));  // znak stopni
          lcd.print(" ");
        }
        else {
          lcd.setCursor(0, 0);
          lcd.print("T.SET:");
          lcd.print(Zadana);
          lcd.setCursor(9, 0);  
          lcd.write(byte(0));  // znak stopni
          //lcd.print(" ");
          }
      
        lcd.setCursor(10, 0);
        lcd.print(" ");
        lcd.print((char)126);  // strzałki
        lcd.print(" ");
        if (temp_aht==-127 ){
          lcd.print(" 0");
          lcd.write(byte(0));
        }
        else{
          lcd.print(temp_aht, 1);
          lcd.write(byte(0));  // znak stopni
        }
        //lcd.print(" ");

        lcd.setCursor(0, 1);
        lcd.print(" ");
        lcd.write(byte(1));  // Znak dzwonka
        lcd.print(" ");
        print2d(SetCzasGodz);
        lcd.print(':');
        print2d(SetCzasMin);
        lcd.print(" ");
        lcd.print((char)126); 
        lcd.print(" ");
        if(StoperCzasGodz==0 && StoperCzasMin==0 && StoperCzasSek == 0){
        lcd.print("00:00:00");
        }
        else{
        print2d(StoperCzasGodz);
        lcd.print(":");
        print2d(StoperCzasMin);
        lcd.print(":");
        print2d(StoperCzasSek);
        }
        //lcd.print(" ");

        lcd.setCursor(0, 2);
        lcd.print("DS1:");
        printTemp(tempDS_1);
        lcd.print((char)223);  // znak stopni
        lcd.print("C");
        //lcd.write(byte(0));
        lcd.print(" ");
        lcd.print("DS3:");
        printTemp(tempDS_3);
        lcd.print((char)223);  // znak stopni
        lcd.print("C");
        //lcd.write(byte(0));
        //lcd.print("H:");
        //lcd.print(hum.relative_humidity, 1);
        lcd.print(" ");
        


        lcd.setCursor(0, 3);
        lcd.print("Humidity: ");
        lcd.print(hum.relative_humidity, 1);
        lcd.print("%    ");
       
       
    
      }

      if (strona == 2) {
        
        lcd.setCursor(0, 0);
        lcd.print("Dane z czujnikow:   ");

        lcd.setCursor(0, 1);
        lcd.print("T_aht:");
        lcd.print(temp_aht, 1);
        lcd.write(byte(0));  // znak stopni
        lcd.print(" H:");
        lcd.print(hum.relative_humidity, 1);lcd.print("% "); 

        lcd.setCursor(0, 2);
        lcd.print("T_bmp:");
        lcd.print(t_bmp, 1);
        lcd.write(byte(0));  // znak stopni
        lcd.print(" P:");
        lcd.print(p_hPa, 0);
        lcd.print("hPa");

        lcd.setCursor(0, 3);
        lcd.print("T1");
        printTemp(tempDS_1);
        lcd.write(byte(0));
        lcd.print(" T2");
        printTemp(tempDS_2);
        lcd.write(byte(0));
        lcd.print(" T3");
        printTemp(tempDS_3);
        lcd.write(byte(0));
      }
      if (strona == 3) {
        // Linia 2: ciśnienie (z BMP280) + temp z BMP
        lcd.setCursor(0, 0);
        lcd.print("    Regulator PID   ");
        lcd.setCursor(0, 1);
        lcd.print(" Setpoint: ");
        lcd.print(Setpoint,0);
        lcd.print("       ");
        lcd.setCursor(0, 2);
        lcd.print(" Input: ");
        lcd.print(Input,0);
        lcd.print("          ");
        lcd.setCursor(0, 3);
        lcd.print(" Output: ");
        lcd.print(Output,0);
        lcd.print("          ");
        
      }
      if (strona == 4) {
        lcd.setCursor(0, 0);
        lcd.print("        PWM         ");
        lcd.setCursor(0, 1);  
        lcd.print(" FAN: ");
        lcd.print(FAN_MOC);
        lcd.print("%           ");  // znak stopni
        lcd.setCursor(0, 2);  
        lcd.print(" FAN_PWM:  ");
        lcd.print(RAW);
        lcd.print("      ");
        lcd.setCursor(0, 3);
        lcd.print(" COOK_PWM:  ");
        lcd.print(COOK_RAW);
        lcd.print("       ");

      }
      if (tryb == 1) {
        lcd.setCursor(0, 0);
        lcd.printf("Tryb: %d               ", tryb);
        lcd.setCursor(0, 1);
        lcd.print("      DRYING          ");
        Serial.printf("TRYB: %d\n", tryb);
      }
      if (tryb == 2) {
        lcd.setCursor(0, 0);
        lcd.printf("Tryb: %d           ", tryb);
        lcd.setCursor(0, 1);
        lcd.print("      MAINT        ");
        Serial.printf("TRYB: %d\n", tryb);
      }
      if (tryb == 3) {
        lcd.setCursor(0, 0);
        lcd.printf("Tryb: %d                 ", tryb);
        lcd.setCursor(0, 1);
        lcd.print("     ECO SLEEP      ");
        Serial.printf("TRYB: %d\n", tryb);
      }
    }
  }
  
  void setPWMpercentCOOK(int bits, int pct) {
    if (pct < 0) pct = 0;
    if (pct > 100) pct = 100;

    // prog rozruchu (duzo 12V wentylatorow nie rusza <30-40%)
    if (pct > 0 && pct < 20) pct = 20;

    int maxv = (1 << bits) - 1;           // np. 1023 dla 10 bit
    int raw = map(pct, 0, 100, 0, maxv);  // % -> raw
    analogWrite(COOK_PWM, raw);           // wyjscie na pin
    COOK_RAW=raw;
  }
  
  void setPWMpercent(int bits, int pct) {
    if (pct < 0) pct = 0;
    if (pct > 100) pct = 100;

    // prog rozruchu (duzo 12V wentylatorow nie rusza <30-40%)
    if (pct > 0 && pct < 20) pct = 20;

    int maxv = (1 << bits) - 1;           // np. 1023 dla 10 bit
    int raw = map(pct, 0, 100, 0, maxv);  // % -> raw
    analogWrite(FAN_PWM, raw);            // wyjscie na pin
    RAW=raw;
  }
  
  void Logika_Wentylator() {

    if ((hum_aht > 50 && hum_aht < 100) && Zadana == temp_aht ) FAN_MOC = 100;
    else if (hum_aht > 40 && hum_aht <= 50 && Zadana == temp_aht) FAN_MOC = 80;
    else if (hum_aht > 30 && hum_aht <= 40 && Zadana == temp_aht) FAN_MOC = 70;
    else if (hum_aht > 0 && hum_aht <= 20 && Zadana == temp_aht) FAN_MOC = 60;
    else FAN_MOC = 100;  // domyslny
    setPWMpercent(resolution, FAN_MOC);

  }

  const uint16_t debounceMs = 50;
  long long CzasINC = 0;
  long long CzasZadana = 0;
  long long CzasPress = 0;
  bool ZadanaFlaga = false;
  bool pStaninc = 1;
  bool StanInc = digitalRead(Increase);


  void TempZadanaUp() {

    if (digitalRead(Increase) == 0 && !ZadanaFlaga && EnterFlaga && strona == 1  ){ 
      CzasZadana = millis();
      CzasPress = CzasZadana;
      ZadanaFlaga = true;
      Zadana = Zadana + 5;
      Zadana = constrain(Zadana, 0, 100);
      Serial.printf("Wartość Zadana to %d\n", Zadana);
      delay(100);
      
    }
    else if (digitalRead(Increase) == 0 && ZadanaFlaga) {
      if (millis() - CzasZadana > 400 && millis() - CzasPress > 200) {
        CzasPress = millis();
        Zadana = Zadana + 5;
        Zadana = constrain(Zadana, 0, 100);
        Serial.printf("Wartość Zadana to %d\n", Zadana);
      }
    }
    if (digitalRead(Increase) == 1 && ZadanaFlaga) {
      ZadanaFlaga = false;
    }
  }
  unsigned long CzasZadanaUp = 0;
  unsigned long CzasPressUp = 0;
  bool ZadanaFlagaUp = false;

  void TempZadanaDown() {

    if ((digitalRead(Decrease) == LOW) && !ZadanaFlagaUp && EnterFlaga && strona == 1 ) { //
      CzasZadanaUp = millis();
      CzasPressUp = CzasZadanaUp;
      ZadanaFlagaUp = true;
      Zadana = Zadana - 5;
      Zadana = constrain(Zadana, 0, 100);
      delay(100);
      Serial.printf("Wartość Zadana to %d\n", Zadana);
    }

    else if ((digitalRead(Decrease) == LOW) && ZadanaFlagaUp) {
      if ((millis() - CzasZadanaUp > 400) && (millis() - CzasPressUp > 200)) {
        CzasPressUp = millis();
        Zadana = Zadana - 5;
        Zadana = constrain(Zadana, 0, 100);
        Serial.printf("Wartość Zadana to %d\n", Zadana);
      }
    }

    if ((digitalRead(Decrease) == HIGH) && ZadanaFlagaUp) {
      ZadanaFlagaUp = false;
    }
  }



  PID pid(&Input, &Output, &Setpoint, Kp, Ki, Kd, DIRECT);

  void COOK() {
     if(tempDS_1 >= TempGraniczna || tempDS_2 >= TempGraniczna || tempDS_3 >= TempGraniczna){
      Zadana = 0;
      strona = 0;
      Setpoint = 0;
      tryb = 0;
      
    lcd.setCursor(0, 1);
    lcd.print("Setpoint: ");
    lcd.print(Setpoint);
    lcd.print("      ");

    lcd.setCursor(0, 2);
    lcd.print("DS1: ");
    lcd.print(tempDS_1, 1);
    lcd.write(byte(0));
    lcd.print("     ");

    lcd.setCursor(0, 3);
    lcd.print("DS3: ");
    lcd.print(tempDS_3, 1);
    lcd.write(byte(0));
    lcd.print("     ");
    delay(1000*60*5);
  }
    
    else {

    Setpoint = Zadana;
    Input = temp_aht;   // ← podmień na swój czujnik (np. temperatura)
    pid.Compute();  // liczy co SetSampleTime ms; wynik w Output (0..100)
    setPWMpercentCOOK(resolution, (int)Output); 
    }
    
    
    
    
  }


  void setup() {
    Serial.begin(119200);
    delay(1000);

    Wire.begin(8, 9);  // I2C do Ekranu/AHT20/BMP280
    Wire.setClock(400000); //odświeżanie I2C
    lcd.init();       // Włącz ekran
    lcd.backlight();  // Ekran ON

    pinMode(PrzyciskEkran, INPUT_PULLUP);  // wewnętrzny pull-up dla przycisku
    pinMode(ONE_WIRE_BUS, INPUT_PULLUP);   // pull-up pod onewire
    pinMode(Increase, INPUT_PULLUP);       // plus wartość zadana
    pinMode(Decrease, INPUT_PULLUP);       // minus wartość zadana
    pinMode(PrzyciskTryb, INPUT_PULLUP);   // przycisk do trybów
    pinMode(Enter, INPUT_PULLUP);          //Przycisk od zatwierdzania
    //LED
    analogWriteResolution(LedPin, resolution);  // 10-bit -> 0..1023
    analogWriteFrequency(LedPin, freq);
    pinMode(LedPin,OUTPUT);                //PWM do ledów
    digitalWrite(LedPin,HIGH);

    sensors.begin();  // start magistrali OneWire
    sensors.setWaitForConversion(false); // tryb nieblokujący (płynna pętla)
    
    //Ustawienie PWM
    analogWriteResolution(FAN_PWM, resolution);  // 10-bit -> 0..1023
    analogWriteFrequency(FAN_PWM, freq);

    //Ustawienie PWM grzałki
    analogWriteResolution(COOK_PWM, resolution);  // 10-bit -> 0..1023
    analogWriteFrequency(COOK_PWM, freqCook);

    
    
                                  // PID
    pid.SetOutputLimits(0, 100);  // WYJŚCIE 0..100
    pid.SetSampleTime(500);       // ms; 
    pid.SetMode(AUTOMATIC);
  }

  void loop() {
   
   
      
    EnterFlagaa();
    TempZadanaDown();
    TempZadanaUp();
    SETCZAS();
    Odliczanie();
    NextStrona();
    NextTryb();
    PomiarZczujnikow();
    ekranOff();
    Logika_Wentylator();
    COOK();
    
    

  }

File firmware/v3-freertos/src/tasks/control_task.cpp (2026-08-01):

#include <Arduino.h>
#include <PID_v1.h>
#include <Preferences.h>


#include "tasks/control_task.h"
#include "rtos_handles.h"
#include "config.h"
#include "tasks/log_task.h"

void vControlTask(void *pvParameters) {

    I2C_sensors i2c_sensors;
    DS_sensors ds_sensors;

    PID_data pid_data;    
    Control_status control_status;
    Preferences preferences;

    preferences.begin("Kp", false);
    pid_data.Kp = preferences.getFloat("Kp", pid_data.Kp);
    preferences.end();
    
    preferences.begin("Ki", false);
    pid_data.Ki = preferences.getFloat("Ki", pid_data.Ki);
    preferences.end();

    preferences.begin("Kd", false);
    pid_data.Kd = preferences.getFloat("Kd", pid_data.Kd);
    preferences.end();

    PID pid(&pid_data.Input, &pid_data.Output, &pid_data.Setpoint, pid_data.Kp, pid_data.Ki, pid_data.Kd, DIRECT);
    
    pid.SetOutputLimits(0, 1023);  
    pid.SetSampleTime(pid_data.SetSampleTime);       
    pid.SetMode(AUTOMATIC);

    ledcSetup(0, pid_data.freq, pid_data.rozdzielczosc);// kanał, freq, rozdzielczość
    ledcAttachPin(Pin::COOK_PWM, 0); // pin, kanał


    double prev_setpoint = pid_data.Setpoint;

    for (;;) {

        xQueuePeek(xSetpointQueue, &pid_data, pdMS_TO_TICKS(Timing::HOLD_MS));

        if(prev_setpoint > 0.0 && pid_data.Setpoint == 0.0) {
            pid.SetMode(MANUAL);
            pid_data.Output = 0;
            pid.SetMode(AUTOMATIC);
        }
        prev_setpoint = pid_data.Setpoint;

        // Dane z czujników I2C
        if(!xQueuePeek(xI2CsensorsQueue,&i2c_sensors, pdMS_TO_TICKS(Timing::HOLD_MS))){
            LOG("Bład przesłania danych z kolejki xI2CsensorsQueue do ControlTask");
        }
        
        // Dane z one-Wire (DS18B20)
        if(!xQueuePeek(xDS18B20Queue,&ds_sensors, pdMS_TO_TICKS(Timing::HOLD_MS))){
            LOG("Bład przesłania danych z kolejki xDS18B20Queue do ControlTask");
        }

        /* Zmina w trakcie działania suszarki */
        pid.SetTunings(pid_data.Kp, pid_data.Ki, pid_data.Kd);
        pid_data.Input = i2c_sensors.temp_aht;

        pid.Compute();
        ledcWrite(0, pid_data.Output); // kanał 0 jest przypisany do pinu COOK_PWM
        //LOG("Output is equail: %.1f",control_status.Output);
               
        control_status.active = (pid_data.Output > 0);


        //Zabezpiecznie przed zbyt wysoką temp. na matach
        if(ds_sensors.DS_1 > Calibration::Max_DS_temperature ||
            ds_sensors.DS_2 > Calibration::Max_DS_temperature ||
            ds_sensors.DS_3 > Calibration::Max_DS_temperature) {
            pid_data.Setpoint = 0.0;
            pid_data.Output = 0.0;
            pid_data.error = true;
            xQueueOverwrite(xSetpointQueue,&pid_data);
            LOG("Zabezpieczenie przed zbyt dużą temperaturą aktywowane pid_data.error = %d",pid_data.error);
        }else if (ds_sensors.DS_1 < Calibration::Temp_after_error &&
                  ds_sensors.DS_2 < Calibration::Temp_after_error &&
                  ds_sensors.DS_3 < Calibration::Temp_after_error && pid_data.error == true)
        {
            pid_data.error = false;
            LOG("Mata wystygła do zadanej temperatury %.1f pid_data.error = %d",Calibration::Temp_after_error,pid_data.error);
        }
        
        

        control_status.Output = pid_data.Output * 100.0f / 1023.0f;
        LOG("Output is equail: %.1f",control_status.Output);
        control_status.Setpoint = pid_data.Setpoint;

        //Wysyłane dane z PID
        xQueueOverwrite(xControlDataQueue,&control_status);

        vTaskDelay(pdMS_TO_TICKS(Timing::PID_COMPUTING));
       
    }
}

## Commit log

2026-03-05 Refactor PID sample time comment for clarity
2026-08-01 pid fix
2026-08-02 repo improvement
    [Cz─Ö┼Ť─ç1.0001.ipt, Cz─Ö┼Ť─ç1.ipt, Cz─Ö┼Ť─ç2.ipt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]
2026-08-02 Change material for base.stl from PETG to ABS
